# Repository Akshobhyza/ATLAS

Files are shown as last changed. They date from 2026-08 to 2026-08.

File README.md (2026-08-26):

Meet ATLAS, an autonomous robot built to find, pickup, and sort objects with absolutely no human control. Combining custom manufacturing, programming, and artificial intelligence, ATLAS is designed as a compact bot made to make your life easier.

Screenshot 2026-08-12 at 11 04 58 AM

<p> For demo links you have to refresh after you click the link </p>
<p> DEMO LINK FOR CHASSIS: https://cad.onshape.com/documents/8344d425af85321919fd70ba/w/e938afa8e847260ac57abb2e/e/849c61a34d9bbbbca970fb94 </p>
<p> DEMO LINK FOR ARM: https://cad.onshape.com/documents/d1ed9956d624a724c1956c00/w/4fc057c3486962ca716a2f76/e/527a2c8adbbe65b72ea021fc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</p>

# KEY FEATURES 
Moves around on its own.
Detects objects in its path using a camera.
Determines which objects it may be able to pick up.
Gives detected objects a confidence score.
Measures how far objects are from the robot.
Uses an arm and claw to pick up objects.
Displays information about what the robot is doing.

# Python V3.11 Required to run firmware
To run code, open a nano inside the Raspberry Pi Python Terminal, and upload the code into the nano, then run the code using python3 (your nano name here) and wait for it to initialize.

# How it works
Atlas is a bot that works through multiple subsystems that all work together to detect, identify and locate objects. The first subsystem is the Raspberry pi.
1. The Pi is connected to a camera located at the base of the robot arm, and when the camera sees an object, it evaluates it using OpenCV to see it the size is small enough to be picked up by the claw.

2. Next it locates the object using pixels on the cameras frames, trained to accuracy using a data table of pixel rages to distances in mm. 
After it identifies the location of the object, it translates it into x and y coordinates, which it then sends to the Arduino in the form of "MOVE X Y Z" (z is always 0.00mm because it has to reach objects on the ground).

3. After that, the Arduino calculates where the arm should move using inverse kinematics and equations (θbase = atan2(X, Y)), which is the distance from the object using the trigonometry, because the Arduino treats the arm segments as x and y components of a right triangle where the line from the base to the object is the hypotenuse.
   
4. It then calculates the distance, and calculates the elbow angle
   (using cos_theta2 = (R^2 - L1^2 - L2^2) / (2 * L1 * L2) and
   theta_2 = acos(max(-1.0, min(1.0, cos_theta2)))).
   
5. It also calculates the distance from the shoulder to the object using the pythagorean theorem, and finds the angle of the shoulder using the equations cos_beta = (R^2 + L1^2 - L2^2) / (2 * R * L1), beta = acos(max(-1.0, min(1.0, cos_beta))), and theta_1 = alpha + beta where theta1 is the intermediate angle of the shoulder joint.

This is how the bot effectively tracks objects and converts the location of said object into physical movement of the robotic arm using physics, inverse kinematics, and a lot of trigonometry.

One important decision I had to make for Atlas was removing the 3rd microcontroller. Before, I was using the Pi and R4, but also an Arduino Uno R3, but I decided to remove the R3 because I realized that it would take up more space, make all the wiring more difficult, and in general make everything more complicated with no need. Previously the R4 was controlling all sensors and screens, and the R3 was controlling the drivetrain and arm (movement related stuff), but now the R4 controls everything. 

# Credits
Raspberry Pi Foundation — Raspberry Pi hardware and camera ecosystem.
Arduino — UNO R4 WiFi microcontroller platform.
TensorFlow — MobileNet SSD / COCO object-detection model.
COCO Dataset — Object-detection classes and training data.
KiCad — Schematic and electronics design.
OpenCV — Camera and computer-vision processing.
Onshore - Robot hardware design.

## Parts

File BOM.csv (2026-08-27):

Item Name | Qty | Price (total) (USD) | Item link | Notes
5PK MG90 Servo | 1 | $18.47 | https://www.aliexpress.us/item/3256812402518701.html?curPageLogUid=i5FYWuN1iW6y | 5 Servos needed for the arm, because MG90's tend to break often
BTS7960 Motor driver | 4 | $21.60 | https://www.aliexpress.us/item/3256810111250919.html?curPageLogUid=0GExkYlOJwMi | Motor drivers, 1 driver per motor
50Pcs Screw Terminal Block | 1 | $5.75 | https://www.aliexpress.us/item/3256811633742862.html?curPageLogUid=8b4JGTJOPP0M | To connect motor driver outputs to breadboard
Silicone tape | 1 | $4.30 | https://www.aliexpress.us/item/3256810005429254.html?curPageLogUid=6p3Jsf825DFj | So that plastic wheels dont slip
On/Off switch 2pc | 1 | $3.73 | https://www.aliexpress.com/ssr/300000512/BundleDeals2?productIds=1005008077525576%3A12000043565748059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 | To turn robot on and off
XT60 Connectors | 1 | $6.82 | https://www.aliexpress.us/item/3256810467314948.html?curPageLogUid=a9O64mJ5LWJT | To connect battery to breaboard
Buck converter 5pcs | 1 | $4.75 | https://www.aliexpress.us/item/3256808492415082.html?curPageLogUid=4GcXAPN06Oy0 | To step down 11.1V motor battery voltage to a suitable 5V
LCD Screen 1pcs | 1 | $4.46 | https://www.aliexpress.us/item/3256812410321021.html?curPageLogUid=3s61Orf3QA3L | To display stats
Distance sensor 5pk | 1 | $7.76 | https://www.aliexpress.us/item/3256808625237519.html?curPageLogUid=cM6mQ6ALyCPs | Avoid crashes
Screw Kit M3 | 1 | $7.97 | https://www.aliexpress.us/item/3256806829044148.html?curPageLogUid=nCsk0pBcJ5z7 | Put everything together
LiPo Battery Balance Charger | 1 | $16.99 | https://www.amazon.com/gp/product/B0FPDJP4GK/ref=ox_sc_act_title_13?smid=A3OUEA3BPILM2W&psc=1 | To charge the LiPo batteries
LiPo Battery 11.1V 3S 2pck | 1 | $37.99 | https://www.amazon.com/gp/product/B0BYNSH6Q7/ref=ox_sc_act_title_12?smid=A646DVGSXYMNH&psc=1 | Powers the whole robot
Total Price (USD): | $140.59

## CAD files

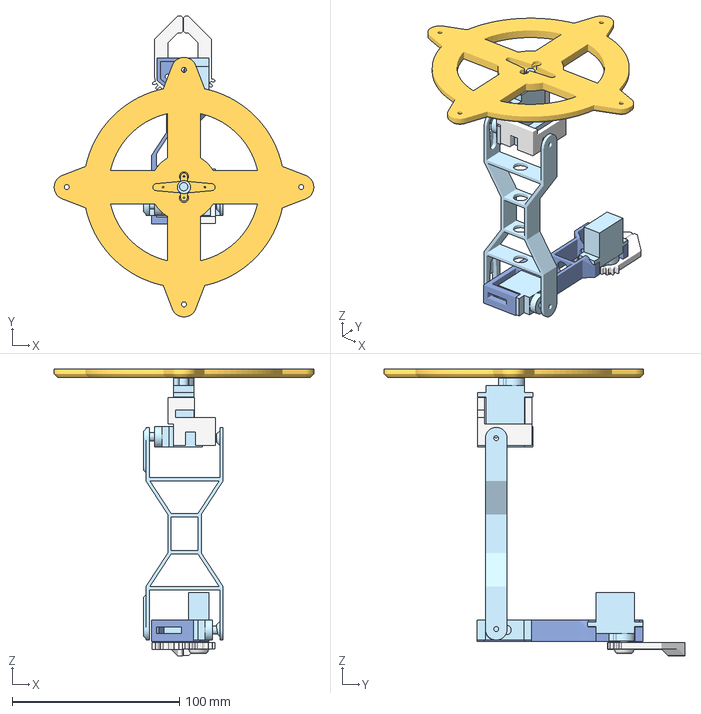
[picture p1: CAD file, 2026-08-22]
CAD/ATLAS ARM.step
154.9 x 179.6 x 171.4 mm
Servo SG90 x 4

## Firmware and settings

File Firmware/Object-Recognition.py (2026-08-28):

from flask import Flask, Response, render_template_string, request, jsonify
from picamera2 import Picamera2
import cv2
import numpy as np
import threading
import time
import serial

app = Flask(__name__)

# ============================================================
# CAMERA
# ============================================================

picam2 = Picamera2()

config = picam2.create_video_configuration(
    main={
        "size": (640, 480),
        "format": "RGB888"
    }
)

picam2.configure(config)
picam2.start()

time.sleep(2)

WIDTH = 640
HEIGHT = 480

ROTATE_90 = True


# ============================================================
# R4 SERIAL
# ============================================================

SERIAL_PORT = "/dev/ttyACM0"
SERIAL_BAUD = 115200

r4 = None

try:
    r4 = serial.Serial(
        SERIAL_PORT,
        SERIAL_BAUD,
        timeout=1
    )

    time.sleep(2)
    r4.reset_input_buffer()
    r4.reset_output_buffer()

    print("R4 connected on", SERIAL_PORT)

except Exception as e:
    print("WARNING: Could not connect to R4")
    print(e)


def send_to_r4(command):
    global r4

    if r4 is None:
        print("R4 NOT CONNECTED:", command)
        return False

    try:
        message = command.strip() + "\n"

        r4.write(message.encode("utf-8"))
        r4.flush()
        
        time.sleep(0.05)

        print("R4 <-", command)

        return True

    except Exception as e:
        print("R4 SERIAL ERROR:", e)
        try:
            r4.close()
            r4.open()
            time.sleep(2)
        except:
            pass

        return False


# ============================================================
# GLOBALS
# ============================================================

lock = threading.Lock()

latest_jpeg = None
live_detections = []


# ============================================================
# CAMERA
# ============================================================

def capture_frame():
    frame = picam2.capture_array()

    frame = cv2.cvtColor(
        frame,
        cv2.COLOR_RGB2BGR
    )

    if ROTATE_90:
        frame = cv2.rotate(
            frame,
            cv2.ROTATE_90_CLOCKWISE
        )

    return frame


# ============================================================
# CAMERA -> ROBOT COORDINATES
# ============================================================

def get_center_camera_x(camera_y):
    points = [
        (103.0, 339.0),
        (183.0, 328.0),
        (263.0, 357.0)
    ]

    if camera_y <= points[0][0]:
        y1, x1 = points[0]
        y2, x2 = points[1]

    elif camera_y >= points[-1][0]:
        y1, x1 = points[-2]
        y2, x2 = points[-1]

    else:
        for i in range(
            len(points) - 1
        ):
            y1, x1 = points[i]
            y2, x2 = points[i + 1]

            if y1 <= camera_y <= y2:
                break

    if y2 == y1:
        return x1

    ratio = (
        (camera_y - y1) /
        (y2 - y1)
    )

    return x1 + ratio * (x2 - x1)


def estimate_robot_y(camera_y):
    camera_points = np.array(
        [
            100.0,  # Top of your workspace view
            400.0   # Bottom of your workspace view
        ],
        dtype=float
    )

    robot_points = np.array(
        [
            200.0,  # Max Y distance
            120.0   # Min Y distance
        ],
        dtype=float
    )

    robot_y = float(
        np.interp(
            camera_y,
            camera_points,
            robot_points,
            left=200.0,
            right=120.0
        )
    )

    return max(120.0, min(200.0, robot_y))


def estimate_robot_x(
    camera_x,
    camera_y
):
    center_x = get_center_camera_x(
        camera_y
    )

    pixel_offset = (
        center_x - camera_x
    )

    pixels_per_mm = 3.5

    x_offset_mm = pixel_offset / pixels_per_mm

    robot_y = estimate_robot_y(
        camera_y
    )

    depth_scale = (
        120.0 /
        max(robot_y, 1.0)
    )

    return float(
        x_offset_mm *
        depth_scale
    )


def camera_to_robot(
    camera_x,
    camera_y
):
    robot_x = estimate_robot_x(
        camera_x,
        camera_y
    )

    robot_y = estimate_robot_y(
        camera_y
    )

    return robot_x, robot_y


# ============================================================
# MANUAL REFERENCE CAPTURE BACKGROUND SUBTRACTION
# ============================================================

stored_background = None

def set_background_reference(frame):
    global stored_background
    stored_background = cv2.GaussianBlur(frame.astype(np.float32), (11, 11), 0)
    print("New empty background reference captured.")


def detect_objects(frame):
    global stored_background

    if stored_background is None:
        stored_background = cv2.GaussianBlur(frame.astype(np.float32), (11, 11), 0)

    current_blur = cv2.GaussianBlur(frame.astype(np.float32), (11, 11), 0)
    
    diff = cv2.absdiff(current_blur, stored_background)
    diff_gray = cv2.cvtColor(diff.astype(np.uint8), cv2.COLOR_BGR2GRAY)

    _, thresh = cv2.threshold(diff_gray, 45, 255, cv2.THRESH_BINARY)
    
    kernel = np.ones((7, 7), np.uint8)
    thresh = cv2.morphologyEx(thresh, cv2.MORPH_OPEN, kernel, iterations=1)
    thresh = cv2.morphologyEx(thresh, cv2.MORPH_CLOSE, kernel, iterations=2)

    contours, _ = cv2.findContours(
        thresh,
        cv2.RETR_EXTERNAL,
        cv2.CHAIN_APPROX_SIMPLE
    )

    results = []

    for contour in contours:
        area = cv2.contourArea(contour)

        if area < 300 or area > 60000:
            continue

        x, y, w, h = cv2.boundingRect(contour)

        if w < 15 or h < 15:
            continue

        cx = x + w // 2
        contact_y = y + h

        results.append({
            "x": int(x),
            "y": int(y),
            "w": int(w),
            "h": int(h),
            "area": int(area),
            "cx": int(cx),
            "cy": int(contact_y)
        })

    results.sort(key=lambda item: item["area"], reverse=True)

    return results[:5]


# ============================================================
# DRAW LIVE FEED
# ============================================================

def draw_live(frame, detections):
    output = frame.copy()

    for i, detection in enumerate(detections):
        x = detection["x"]
        y = detection["y"]
        w = detection["w"]
        h = detection["h"]

        color = (0, 255, 0) if i == 0 else (0, 0, 255)

        cv2.rectangle(
            output,
            (x, y),
            (x + w, y + h),
            color,
            2
        )

        cv2.circle(
            output,
            (detection["cx"], detection["cy"]),
            5,
            color,
            -1
        )

        label = "Target" if i == 0 else f"Obj {i}"
        cv2.putText(
            output,
            label,
            (x, max(20, y - 5)),
            cv2.FONT_HERSHEY_SIMPLEX,
            0.6,
            color,
            2
        )

    return output


# ============================================================
# CAMERA THREAD
# ============================================================

def camera_loop():
    global latest_jpeg
    global live_detections

    while True:
        frame = capture_frame()
        detections = detect_objects(frame)
        output = draw_live(frame, detections)

        success, encoded = cv2.imencode(
            ".jpg",
            output,
            [cv2.IMWRITE_JPEG_QUALITY, 75]
        )

        if success:
            with lock:
                latest_jpeg = encoded.tobytes()
                live_detections = detections

        time.sleep(0.03)


# ============================================================
# VIDEO STREAM
# ============================================================

def video_stream():
    last_frame = None
    while True:
        with lock:
            frame = latest_jpeg

        if frame is not None and frame != last_frame:
            last_frame = frame
            yield (
                b"--frame\r\n"
                b"Content-Type: image/jpeg\r\n\r\n"
                + frame
                + b"\r\n"
            )

        time.sleep(0.01)


# ============================================================
# WEBSITE
# ============================================================

HTML = """
<!DOCTYPE html>
<html>
<head>
<title>Atlas Arm Control</title>
<style>
body {
    background: #111;
    color: white;
    font-family: Arial;
    text-align: center;
}
.container {
    width: 900px;
    max-width: 95%;
    margin: auto;
}
#camera {
    width: 640px;
    max-width: 100%;
    border: 3px solid #444;
}
button {
    padding: 12px 20px;
    margin: 8px;
    font-size: 17px;
    border: none;
    border-radius: 5px;
    cursor: pointer;
}
.bg-btn {
    background: #0d6efd;
    color: white;
    font-weight: bold;
}
.select {
    background: #198754;
    color: white;
    font-weight: bold;
}
.release {
    background: #ffc107;
    color: black;
    font-weight: bold;
}
#status {
    margin: 20px;
    font-size: 18px;
}
.coordinate {
    background: #183d25;
    margin: 15px;
    padding: 20px;
    border-radius: 8px;
    font-size: 20px;
}
.warning {
    background: #223322;
    padding: 15px;
    margin: 15px;
    border-radius: 8px;
}
</style>
</head>
<body>
<div class="container">
<h1>Atlas Arm Smart Tracking</h1>
<div class="warning">
<b>BACKGROUND REFERENCE LOCK</b>
<br>
Clear the workspace, then click <b>Capture Empty Background</b>. After that, place your object down.
</div>
<img id="camera" src="/video_feed">
<br>
<button class="bg-btn" onclick="captureBackground()">1. CAPTURE EMPTY BACKGROUND</button>
<br>
<button class="select" onclick="moveArmToFirst()">2. GRAB TARGET OBJECT</button>
<button class="release" onclick="releaseArm()">RELEASE & RESET ARM</button>
<div id="status">System ready. Capture empty background first.</div>
<div id="coordinates"></div>
</div>
<script>
async function captureBackground() {
    const status = document.getElementById("status");
    status.innerHTML = "Saving empty background reference...";
    try {
        const response = await fetch("/capture_bg", { method: "POST" });
        const data = await response.json();
        if (data.success) {
            status.innerHTML = "Background reference captured! Place your object down.";
        } else {
            status.innerHTML = "Failed to capture background.";
        }
    } catch (error) {
        status.innerHTML = "REQUEST FAILED: " + error;
    }
}
async function moveArmToFirst() {
    const status = document.getElementById("status");
    status.innerHTML = "Moving arm to target...";
    try {
        const response = await fetch("/move_target", {
            method: "POST",
            headers: { "Content-Type": "application/json" },
            body: JSON.stringify({ index: 0 })
        });
        const data = await response.json();
        if (!data.success) {
            status.innerHTML = "Move failed: " + data.error;
            return;
        }
        const target = data.target;
        status.innerHTML = "ARM COMMAND SENT SUCCESSFULLY";
        document.getElementById("coordinates").innerHTML = `
            <div class="coordinate">
                <b>TARGET POSITION</b>
                <br><br>
                Camera: (${target.cx}, ${target.cy})
                <br><br>
                Robot X: <b>${target.robot_x.toFixed(1)} mm</b>
                <br>
                Robot Y: <b>${target.robot_y.toFixed(1)} mm</b>
            </div>
        `;
    } catch (error) {
        status.innerHTML = "REQUEST FAILED: " + error;
    }
}
async function releaseArm() {
    const status = document.getElementById("status");
    status.innerHTML = "Resetting arm position...";
    try {
        const response = await fetch("/release", { method: "POST" });
        const data = await response.json();
        if (data.success) {
            status.innerHTML = "Arm reset command sent.";
        } else {
            status.innerHTML = "Reset failed: " + data.error;
        }
    } catch (error) {
        status.innerHTML = "REQUEST FAILED: " + error;
    }
}
</script>
</body>
</html>
"""


# ============================================================
# FLASK ROUTES
# ============================================================

@app.route("/")
def index():
    return render_template_string(HTML)


@app.route("/video_feed")
def video_feed():
    return Response(
        video_stream(),
        mimetype="multipart/x-mixed-replace; boundary=frame"
    )


@app.route("/capture_bg", methods=["POST"])
def capture_bg():
    try:
        frame = capture_frame()
        set_background_reference(frame)
        return jsonify({"success": True})
    except Exception as error:
        return jsonify({"success": False, "error": str(error)}), 500


@app.route("/move_target", methods=["POST"])
def move_target():
    global live_detections

    try:
        with lock:
            current_detections = list(live_detections)

        if not current_detections:
            return jsonify({
                "success": False,
                "error": "No objects detected against the background. Make sure you captured the empty background first."
            }), 400

        target = current_detections[0]

        robot_x, robot_y = camera_to_robot(target["cx"], target["cy"])
        robot_x -= 40  # calibration offset

        target["robot_x"] = robot_x
        target["robot_y"] = robot_y

        if abs(robot_x) > 150 or robot_y < 50 or robot_y > 400:
            return jsonify({
                "success": False,
                "error": "Detected object is out of safe physical reach bounds."
            }), 400

        command = f"MOVE {robot_x:.1f} {robot_y:.1f} 0.0"
        serial_success = send_to_r4(command)

        return jsonify({
            "success": True,
            "target": target,
            "serial_sent": serial_success
        })

    except Exception as error:
        print("MOVE ERROR:", repr(error))
        return jsonify({"success": False, "error": str(error)}), 500


@app.route("/release", methods=["POST"])
def release():
    try:
        command = "RESET"
        serial_success = send_to_r4(command)

        return jsonify({
            "success": True,
            "serial_sent": serial_success
        })

    except Exception as error:
        print("RELEASE ERROR:", repr(error))
        return jsonify({"success": False, "error": str(error)}), 500


# ============================================================
# MAIN
# ============================================================

if __name__ == "__main__":
    camera_thread = threading.Thread(
        target=camera_loop,
        daemon=True
    )
    camera_thread.start()

    app.run(
        host="0.0.0.0",
        port=5000,
        threaded=True
    )

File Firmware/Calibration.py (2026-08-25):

from flask import Flask, Response, render_template_string, request, jsonify
from picamera2 import Picamera2
import cv2
import numpy as np
import threading
import time

app = Flask(__name__)

# ============================================================
# CAMERA
# ============================================================

picam2 = Picamera2()

config = picam2.create_video_configuration(
    main={
        "size": (640, 480),
        "format": "RGB888"
    }
)

picam2.configure(config)
picam2.start()

time.sleep(2)

WIDTH = 640
HEIGHT = 480

ROTATE_180 = True

# Camera mount area
MOUNT_Y = 440

# ============================================================
# GLOBALS
# ============================================================

lock = threading.Lock()

latest_jpeg = None
background = None

live_candidates = []

selected_candidate = None
calibration_distance = None


# ============================================================
# CAPTURE FRAME
# ============================================================

def capture_frame():

    frame = picam2.capture_array()

    frame = cv2.cvtColor(
        frame,
        cv2.COLOR_RGB2BGR
    )

    if ROTATE_180:
        frame = cv2.rotate(
            frame,
            cv2.ROTATE_180
        )

    return frame


# ============================================================
# CAPTURE BACKGROUND
# ============================================================

def make_background():

    global background

    frames = []

    print("Capturing background...")

    for i in range(10):

        frame = capture_frame()

        frame = cv2.GaussianBlur(
            frame,
            (9, 9),
            0
        )

        frames.append(
            frame.astype(np.float32)
        )

        time.sleep(0.05)

    background = np.median(
        np.stack(frames),
        axis=0
    ).astype(np.uint8)

    print("Background captured.")

    return True


# ============================================================
# DETECT OBJECTS
# ============================================================

def detect_objects(frame):

    if background is None:
        return []

    current = cv2.GaussianBlur(
        frame,
        (9, 9),
        0
    )

    bg = cv2.GaussianBlur(
        background,
        (9, 9),
        0
    )

    diff = cv2.absdiff(
        current,
        bg
    )

    gray = cv2.cvtColor(
        diff,
        cv2.COLOR_BGR2GRAY
    )

    # Difference threshold
    _, mask = cv2.threshold(
        gray,
        30,
        255,
        cv2.THRESH_BINARY
    )

    # Remove tiny noise
    kernel_small = np.ones(
        (7, 7),
        np.uint8
    )

    mask = cv2.morphologyEx(
        mask,
        cv2.MORPH_OPEN,
        kernel_small,
        iterations=1
    )

    # Join parts of same object
    kernel_large = np.ones(
        (13, 13),
        np.uint8
    )

    mask = cv2.morphologyEx(
        mask,
        cv2.MORPH_CLOSE,
        kernel_large,
        iterations=2
    )

    # Ignore camera mount
    mask[MOUNT_Y:HEIGHT, :] = 0

    contours, _ = cv2.findContours(
        mask,
        cv2.RETR_EXTERNAL,
        cv2.CHAIN_APPROX_SIMPLE
    )

    results = []

    for contour in contours:

        area = cv2.contourArea(
            contour
        )

        # Don't make this too aggressive
        if area < 300:
            continue

        if area > 120000:
            continue

        x, y, w, h = cv2.boundingRect(
            contour
        )

        if w < 12 or h < 12:
            continue

        if y >= MOUNT_Y:
            continue

        rect_area = w * h

        if rect_area <= 0:
            continue

        fill = area / rect_area

        if fill < 0.08:
            continue

        aspect = max(
            w / h,
            h / w
        )

        if aspect > 12:
            continue

        cx = x + w // 2
        cy = y + h // 2

        results.append({
            "x": int(x),
            "y": int(y),
            "w": int(w),
            "h": int(h),
            "area": int(area),
            "cx": int(cx),
            "cy": int(cy),
            "fill": float(fill)
        })

    results.sort(
        key=lambda x: x["area"],
        reverse=True
    )

    return results[:15]


# ============================================================
# ANALYZE FRESH FRAMES
# ============================================================

def analyze_fresh_frames():

    all_detections = []

    print()
    print("Analyzing fresh frames...")

    for i in range(5):

        frame = capture_frame()

        detections = detect_objects(
            frame
        )

        print(
            f"Analysis frame {i}: "
            f"{len(detections)} candidates"
        )

        for d in detections:
            all_detections.append(d)

        time.sleep(0.05)

    if not all_detections:
        print("No candidates found.")
        return []

    # ========================================================
    # GROUP NEARBY DETECTIONS
    # ========================================================

    groups = []

    for d in all_detections:

        matched = False

        for group in groups:

            gx = group[0]["cx"]
            gy = group[0]["cy"]

            distance = (
                (d["cx"] - gx) ** 2 +
                (d["cy"] - gy) ** 2
            ) ** 0.5

            if distance < 50:

                group.append(d)
                matched = True
                break

        if not matched:

            groups.append([d])

    final = []

    for group in groups:

        # Need to appear in multiple frames
        if len(group) < 2:
            continue

        # Average position
        cx = int(
            np.mean(
                [x["cx"] for x in group]
            )
        )

        cy = int(
            np.mean(
                [x["cy"] for x in group]
            )
        )

        w = int(
            np.mean(
                [x["w"] for x in group]
            )
        )

        h = int(
            np.mean(
                [x["h"] for x in group]
            )
        )

        area = int(
            np.mean(
                [x["area"] for x in group]
            )
        )

        fill = float(
            np.mean(
                [x["fill"] for x in group]
            )
        )

        final.append({
            "x": cx - w // 2,
            "y": cy - h // 2,
            "w": w,
            "h": h,
            "area": area,
            "cx": cx,
            "cy": cy,
            "fill": fill,
            "hits": len(group)
        })

    final.sort(
        key=lambda x: x["area"],
        reverse=True
    )

    return final[:10]


# ============================================================
# DRAW LIVE FEED
# ============================================================
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

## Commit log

2026-08-19 Added Chassis CAD File
    [Main.step]
2026-08-21 Made Schematic
    [ATLAS Schematic.kicad_sch]
2026-08-22 Revise Atlas project description in README
    Updated the description of Atlas to provide more details on its functionality and design choices, including the use of OpenCV for object recognition and the decision to remove the Arduino Uno R3.
2026-08-22 CADded robotic arm for ATLAS
    [ATLAS ARM.step]
2026-08-22 Update README with additional demo links
    Added demo links for chassis and arm to README.
2026-08-22 Create ATLAS BOM with item details and pricing
    Added a bill of materials (BOM) for the robot project, including item names, quantities, prices, links, and notes.
    [ATLAS BOM - Sheet1.csv, ATLAS BOM.csv]
2026-08-24 Integrate serial communication and Flask for control
    Refactor object recognition code to integrate serial communication, threading, and Flask web server for real-time video streaming and manual control.
2026-08-25 Rename ATLAS ARM.step to CAD/ATLAS ARM.step
    [ATLAS ARM.step]
2026-08-25 Rename ATLAS BOM.csv to BOM/ATLAS BOM.csv
    [ATLAS BOM.csv]
2026-08-25 Rename ATLAS Schematic.kicad_sch to Wiring/ATLAS Schematic.kicad_sch
    [ATLAS Schematic.kicad_sch]
2026-08-25 Add Arduino code for servo control and commands
2026-08-26 Update fmt.Println message from 'Hello' to 'Goodbye'
2026-08-26 Refactor Arduino code for robot arm control
    Refactor servo pin definitions and improve code organization. Added inverse kinematics calculations and enhanced command parsing for better functionality.
2026-08-26 Enhance Atlas description in README
    Expanded the explanation of Atlas's object detection and manipulation process, detailing the subsystems involved and the calculations for robotic arm movement.
2026-08-27 Rename ATLAS BOM - Sheet1-2.csv to ATLAS BOM
2026-08-28 Adjust robot arm parameters and initial positions
